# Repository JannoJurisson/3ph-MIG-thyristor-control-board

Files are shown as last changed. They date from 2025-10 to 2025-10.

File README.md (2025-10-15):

# 3ph-MIG-thyristor-control-board
Control board for my DIY 3 phase MIG welder that uses six thyristors(SCR) for rectifying the output of a old, soviet era three phase isolation transformer (~5kW). 
Raspberry Pico board is used to monitor and control all the functions

## Board Specifications

| Feature | Description |
| :--- | :--- |
| **Power Input** | +24V DC |
| **Current Control** | Potentiometer adjustment for welding current. |
| **Phase Monitoring** | Isolated inputs for all phases for missing phase detection. |
| **SCR Drive** | Isolated output for six SCRs via ferrite transformers (20KHz). |
| **High-Current Outputs** | Gas solenoid, Main Contactor, Auxiliary Output. |
| **Motor Drivers** | 2x `DRV8825` stepper motor drivers. |
| **User Inputs** | Gun trigger switch, ADC for wire speed/current pots. |
| **Expansion** | `I2C` connector for displays and peripherals. |
| **Special Feature**| Wire motor balancing for dual-motor setups (e.g., spool gun).|

3ph_thyristor controller_top

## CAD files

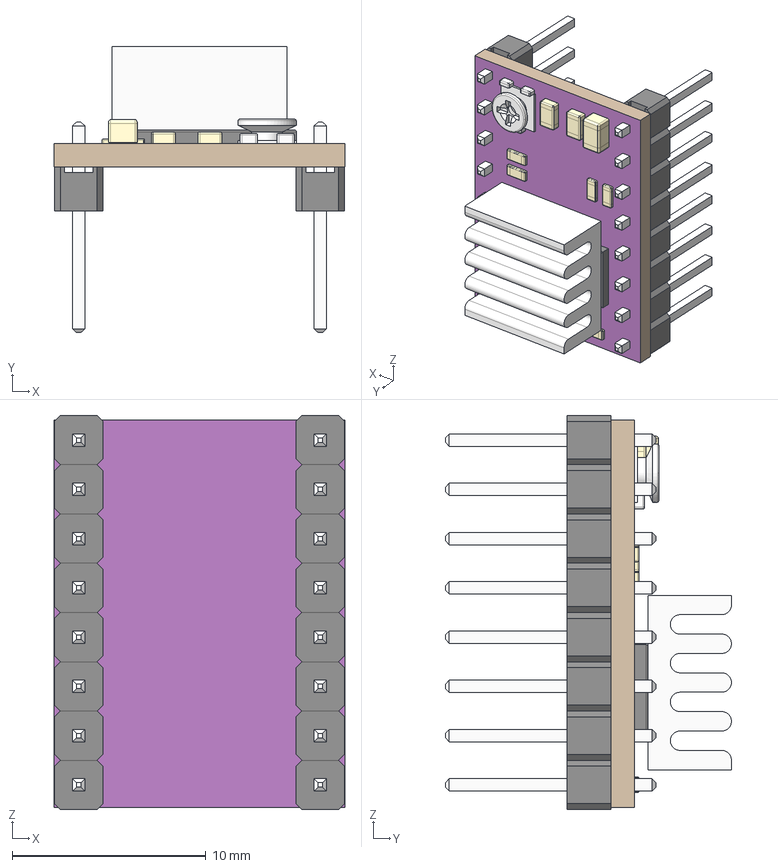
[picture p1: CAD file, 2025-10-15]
KiCAD/3d_models/Driver DRV8825.stp
15.0 x 14.7 x 20.3 mm

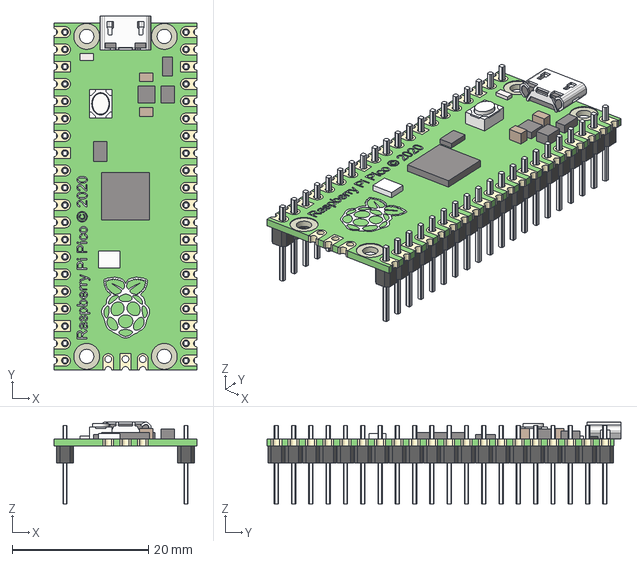
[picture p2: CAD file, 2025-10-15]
KiCAD/3d_models/raspberry pi pico with contacts.step
21.0 x 52.0 x 12.0 mm
ножка x 20
ножка v3(Mirror) x 20

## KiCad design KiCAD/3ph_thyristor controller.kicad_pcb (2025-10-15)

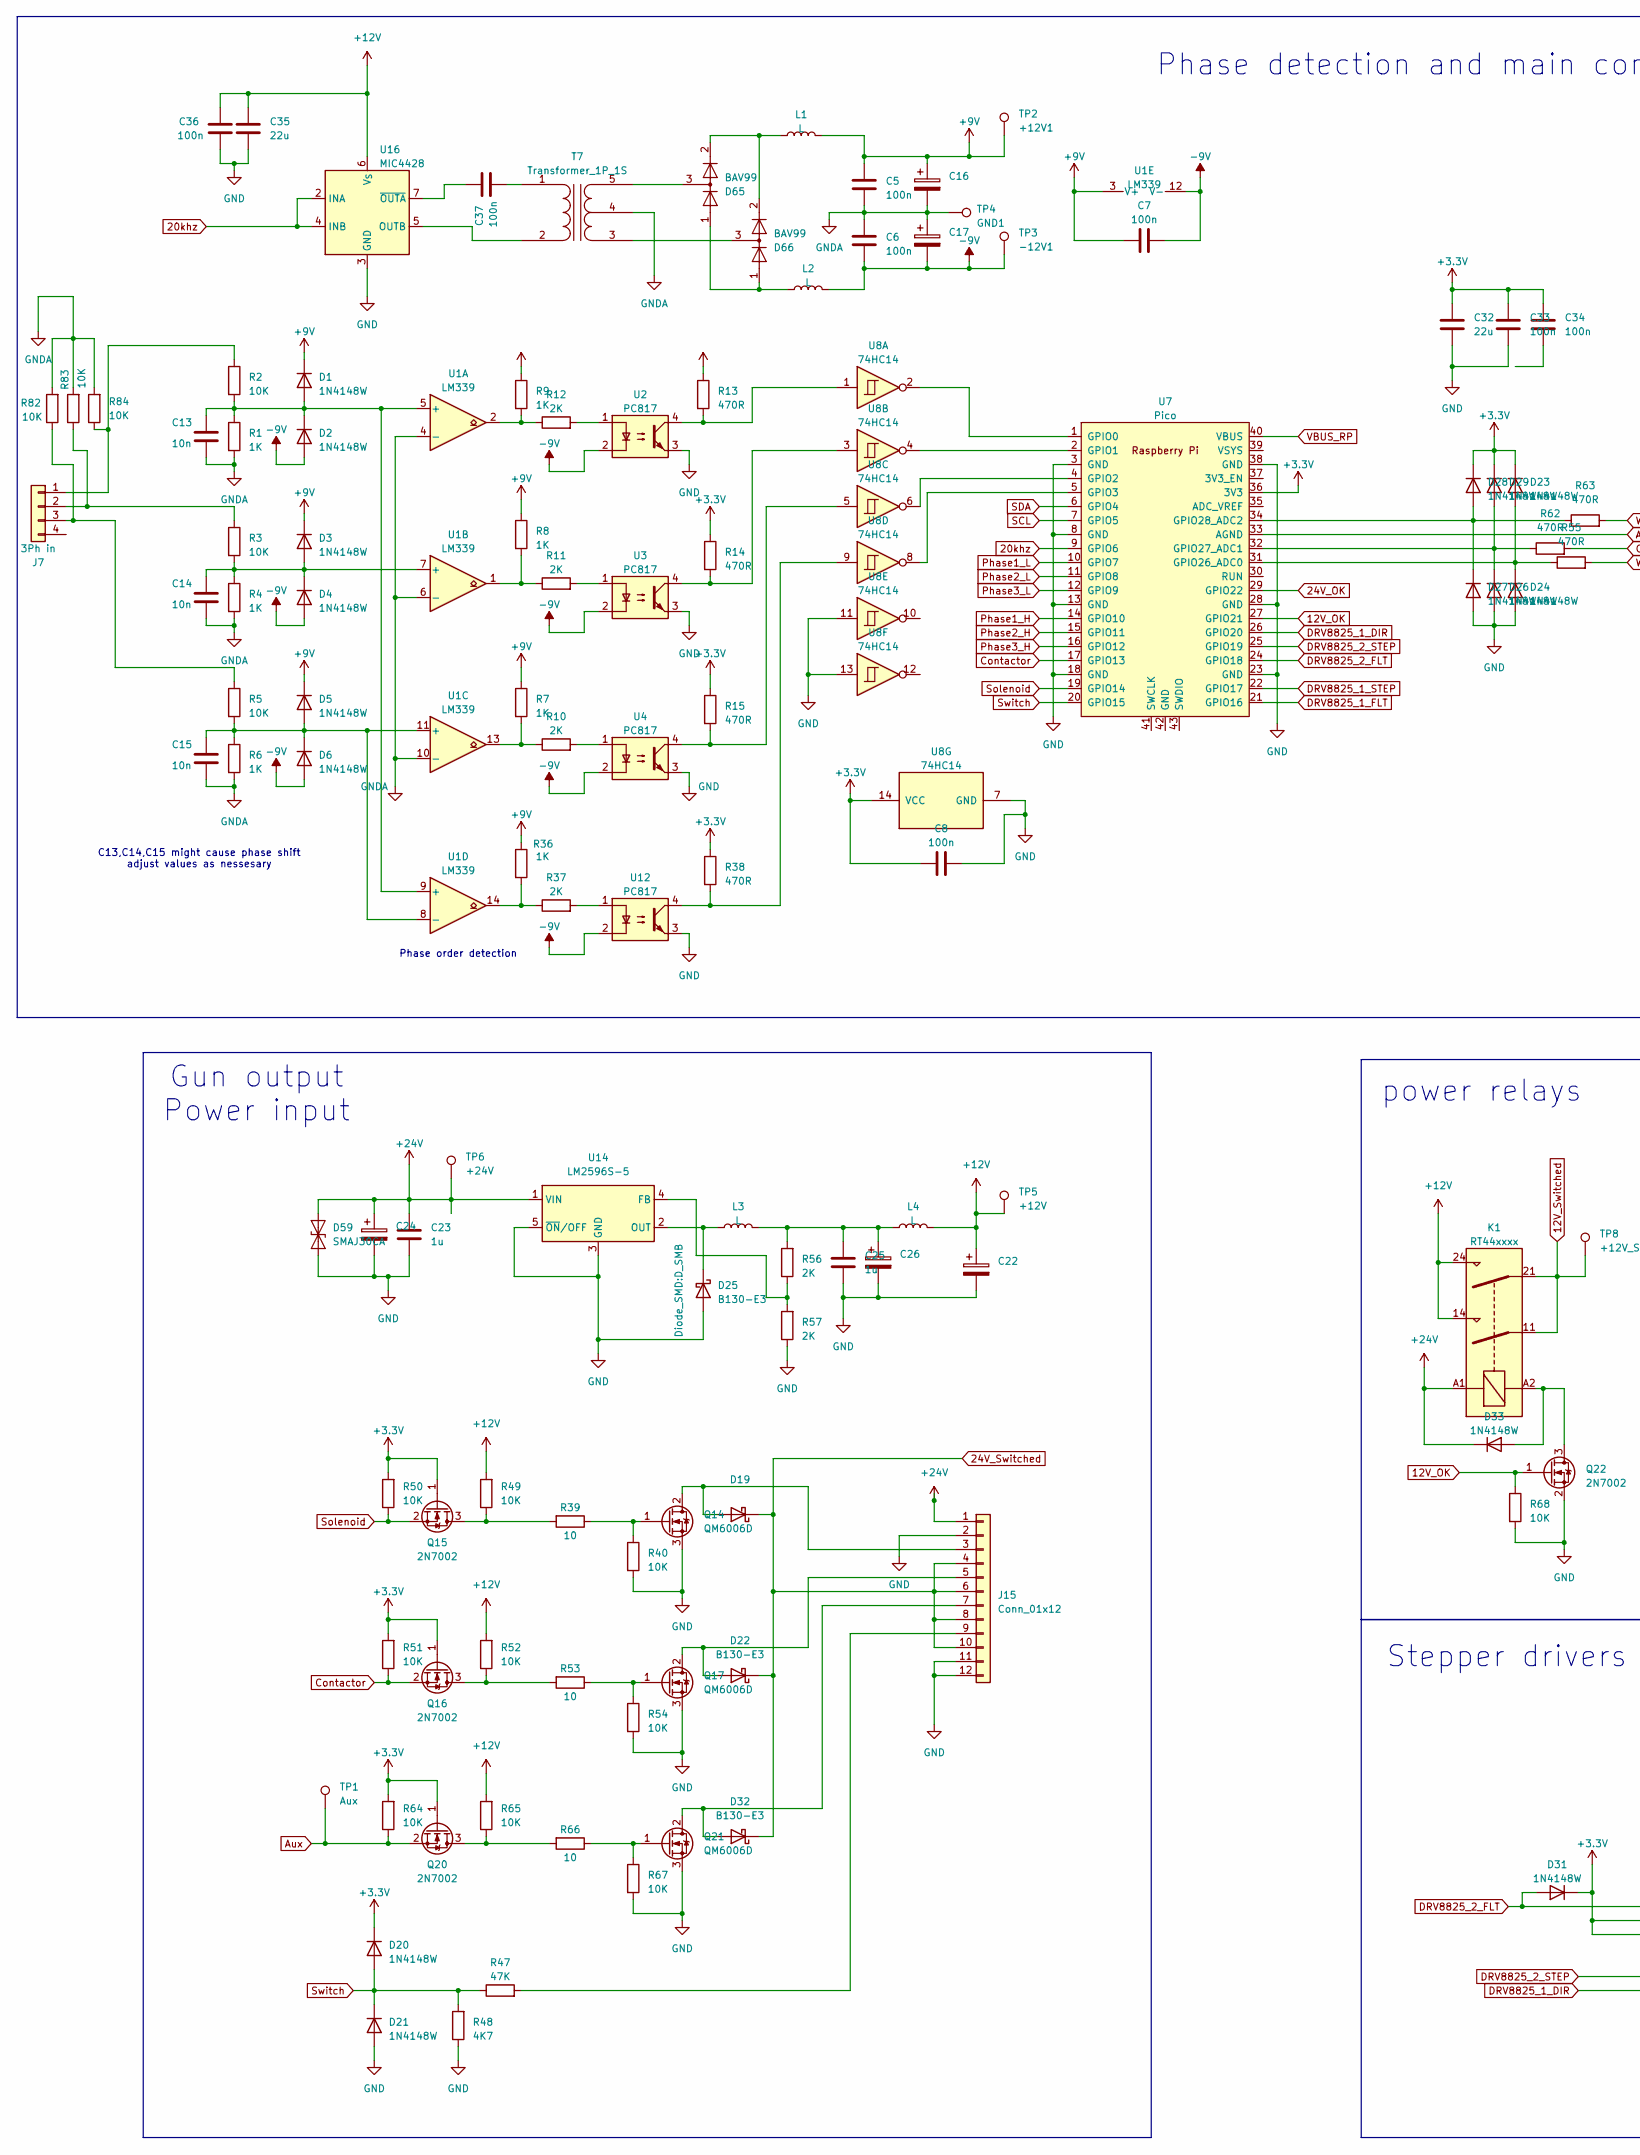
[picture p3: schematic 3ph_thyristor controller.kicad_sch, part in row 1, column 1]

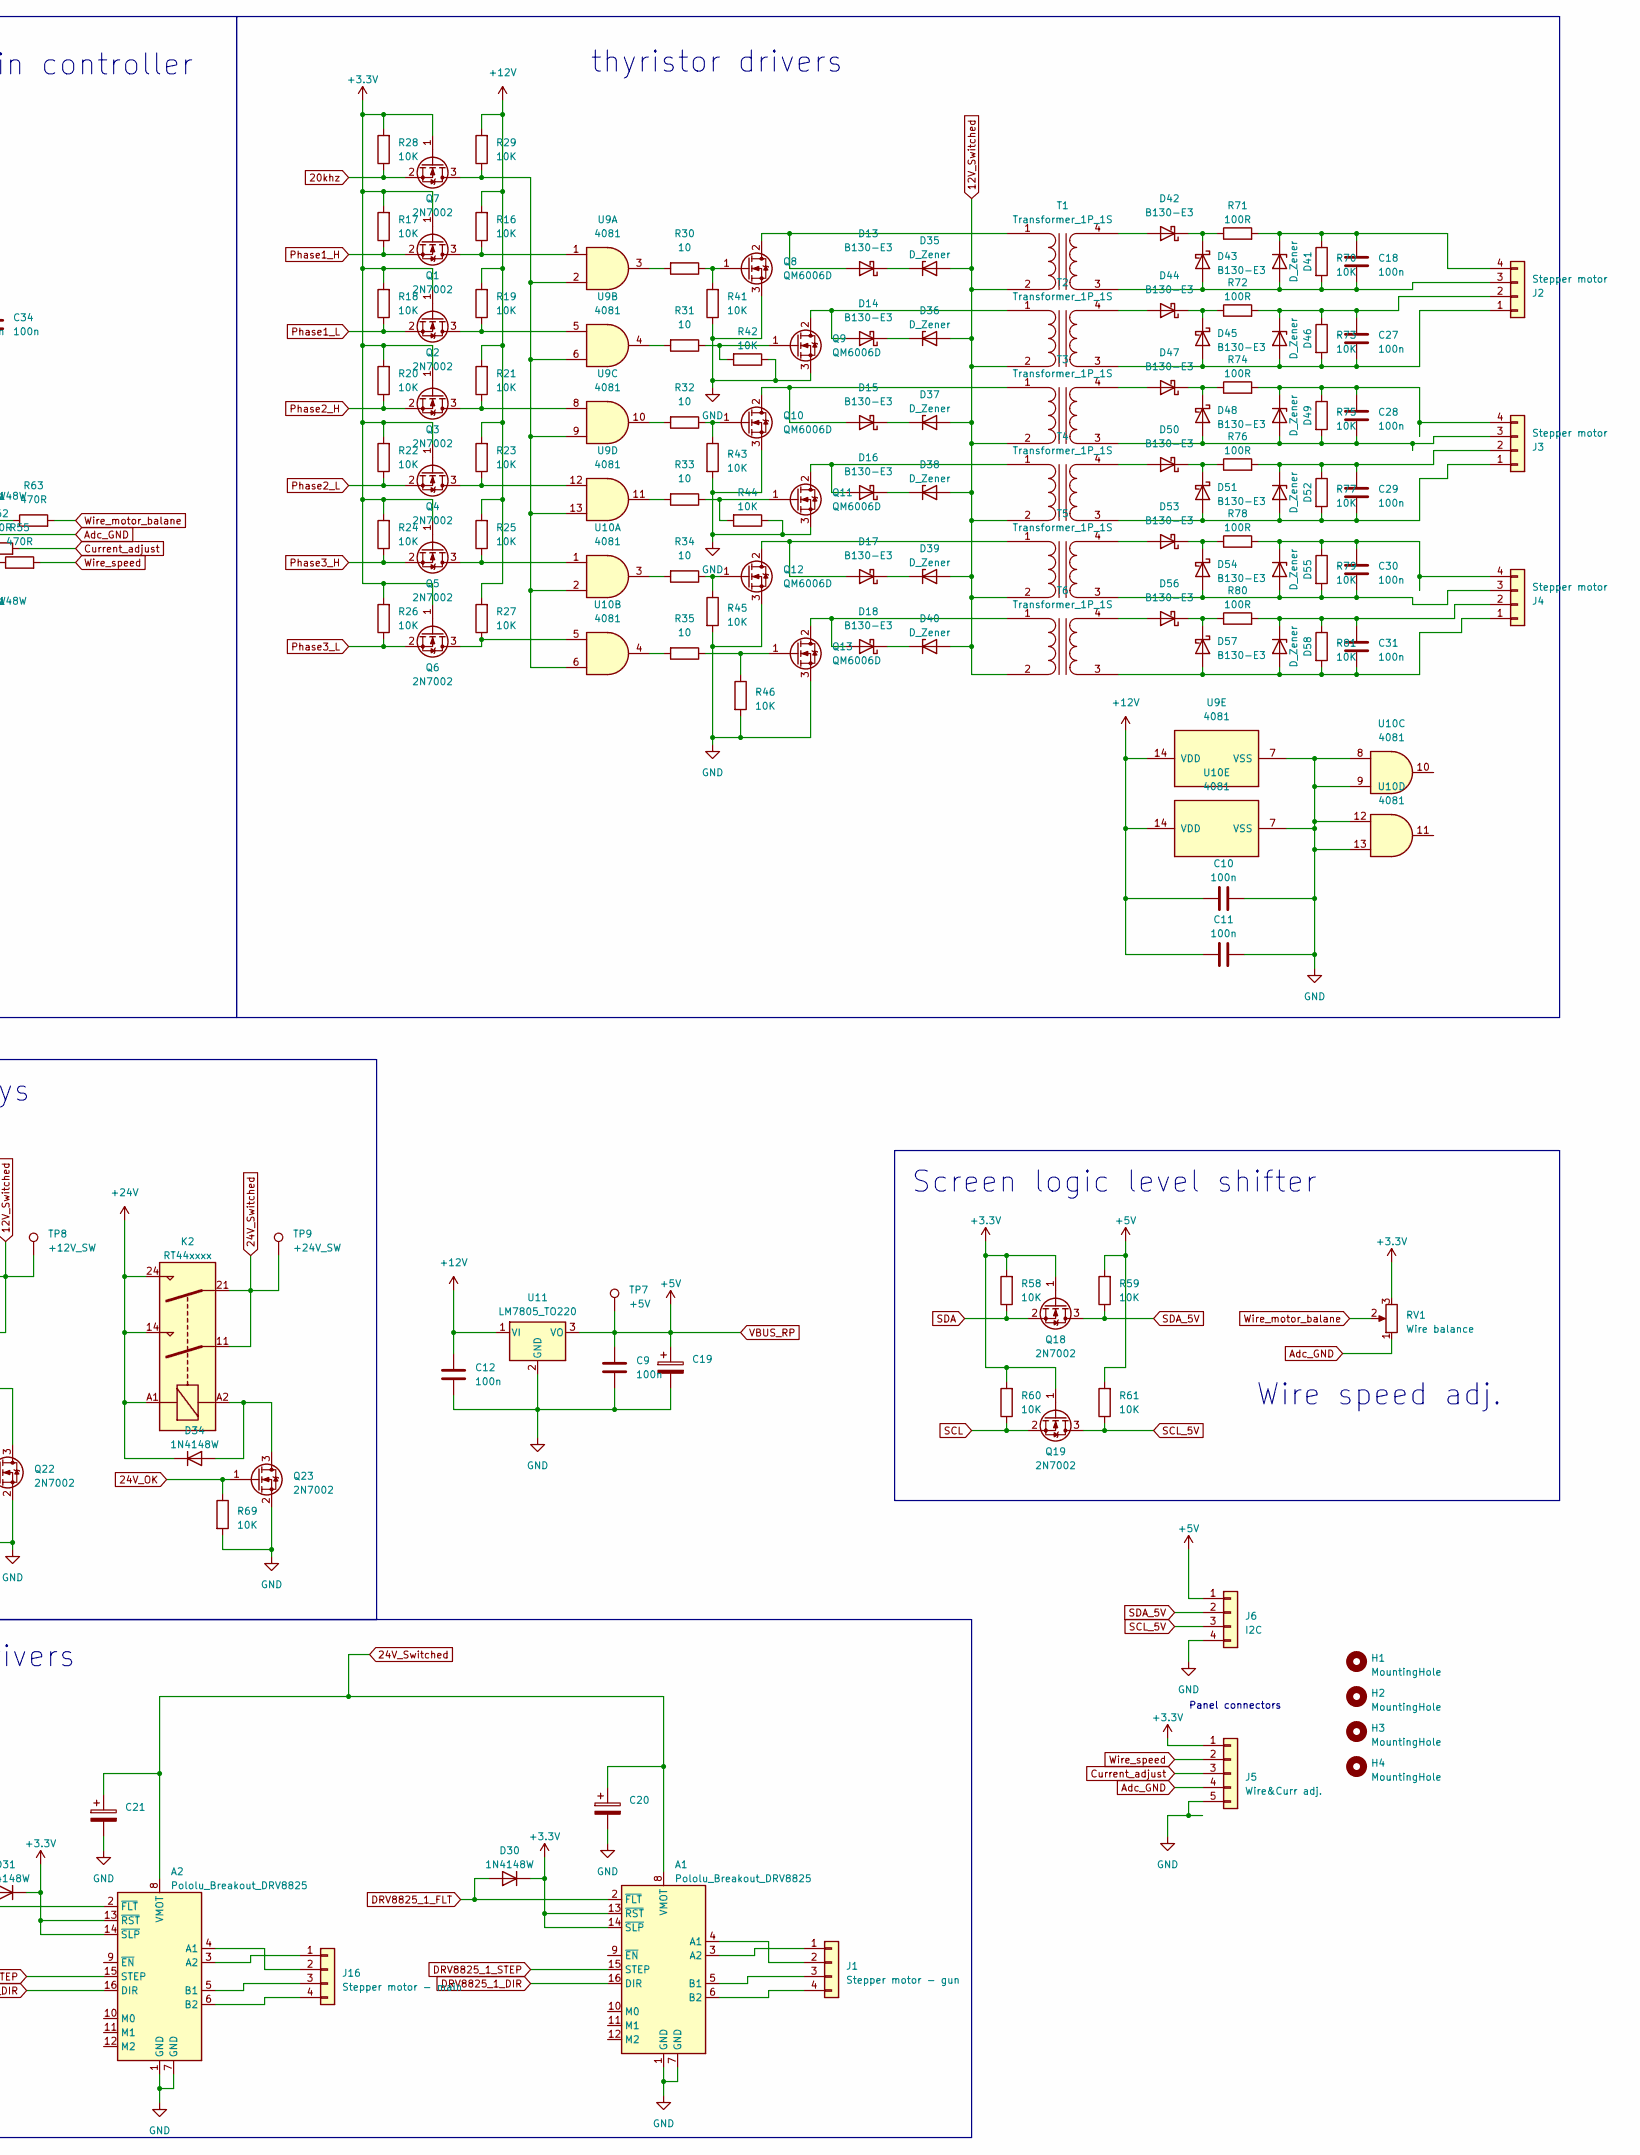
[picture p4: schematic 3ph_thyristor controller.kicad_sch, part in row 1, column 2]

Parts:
A1, A2: Pololu_Breakout_DRV8825; Pololu_Breakout-16_15.2x20.3mm
C5, C6, C7, C8, C9, C10, C11, C12, C18, C27, C28, C29, C30, C31, C33, C34, C36, C37: 100n; C_0805_2012Metric
C13, C14, C15: 10n; C_0805_2012Metric
C16, C17, C19, C20, C21: C_Polarized; CP_Elec_10x10
C22, C24, C26: 220u; CP_Elec_10x10
C23, C25: 1u; C_1206_3216Metric
C32, C35: 22u; C_0805_2012Metric
D1, D2, D3, D4, D5, D6, D20, D21, D23, D24, D26, D27, D28, D29, D30, D31, D33, D34: 1N4148W; D_MiniMELF
D13, D14, D15, D16, D17, D18, D19, D22, D32, D42, D43, D44, D45, D47, D48, D50, D51, D53, D54, D56, D57: B130-E3; D_SMA
D25: B130-E3; D_SMB
D35, D36, D37, D38, D39, D40, D41, D46, D49, D52, D55, D58: D_Zener; D_SMA
D59: SMAJ30CA; D_SMC
D65, D66: BAV99; SOT-23
H1, H2, H3, H4: MountingHole; MountingHole_3.5mm
J1: Stepper motor - gun; PhoenixContact_MSTBA_2,5_4-G_1x04_P5.00mm_Horizontal
J2, J3, J4: Stepper motor; PhoenixContact_MSTBA_2,5_4-G_1x04_P5.00mm_Horizontal
J5: Wire&Curr adj.; Molex_KK-254_AE-6410-05A_1x05_P2.54mm_Vertical
J6: I2C; Molex_KK-254_AE-6410-04A_1x04_P2.54mm_Vertical
J7: 3Ph in; PhoenixContact_MSTBA_2,5_4-G_1x04_P5.00mm_Horizontal
J15: Conn_01x12; PhoenixContact_MC_1,5_12-G-3.5_1x12_P3.50mm_Horizontal
J16: Stepper motor - main; PhoenixContact_MSTBA_2,5_4-G_1x04_P5.00mm_Horizontal
K1, K2: RT44xxxx; Relay_DPST_Schrack-RT2-FormA_RM5mm
L1, L2: L; L_1210_3225Metric_Pad1.42x2.65mm_HandSolder
L3, L4: L; L_Bourns_SRR1260
Q1, Q2, Q3, Q4, Q5, Q6, Q7, Q15, Q16, Q18, Q19, Q20, Q22, Q23: 2N7002; SOT-23
Q8, Q9, Q10, Q11, Q12, Q13, Q14, Q17, Q21: QM6006D; TO-252-2
R1, R4, R6, R7, R8, R9, R36: 1K; R_0805_2012Metric
R2, R3, R5, R16, R17, R18, R19, R20, R21, R22, R23, R24, R25, R26, R27, R28, R29, R40, R41, R42, R43, R44, R45, R46, R49, R50, R51, R52, R54, R58, R59, R60, R61, R64, R65, R67, R68, R69, R70, R73, R75, R77, R79, R81, R82, R83, R84: 10K; R_0805_2012Metric
R10, R11, R12, R37, R56, R57: 2K; R_0805_2012Metric
R13, R14, R15, R38, R55, R62, R63: 470R; R_0805_2012Metric
R30, R31, R32, R33, R34, R35, R39, R53, R66: 10; R_0805_2012Metric
R47: 47K; R_0805_2012Metric
R48: 4K7; R_0805_2012Metric
R71, R72, R74, R76, R78, R80: 100R; R_0805_2012Metric
RV1: Wire balance; Potentiometer_ACP_CA9-V10_Vertical_Hole
T1, T2, T3, T4, T5, T6, T7: Transformer_1P_1S; Transformer_Toroid_Horizontal_D18.0mm
TP1: Aux; TestPoint_Pad_D2.0mm
TP2: +12V1; TestPoint_Pad_D2.0mm
TP3: -12V1; TestPoint_Pad_D2.0mm
TP4: GND1; TestPoint_Pad_D2.0mm
TP5: +12V; TestPoint_Pad_D2.0mm
TP6: +24V; TestPoint_Pad_D2.0mm
TP7: +5V; TestPoint_Pad_D2.0mm
TP8: +12V_SW; TestPoint_Pad_D2.0mm
TP9: +24V_SW; TestPoint_Pad_D2.0mm
U1: LM339; SOIC-14_3.9x8.7mm_P1.27mm
U2, U3, U4, U12: PC817; DIP-4_W7.62mm_SMDSocket_SmallPads
U7: Pico; RPi_Pico_SMD_TH
U8: 74HC14; SOIC-14_3.9x8.7mm_P1.27mm
U9, U10: 4081; SOIC-14_3.9x8.7mm_P1.27mm
U11: LM7805_TO220; TO-252-3_TabPin2
U14: LM2596S-5; TO-263-5_TabPin3
U16: MIC4428; SOIC-8_3.9x4.9mm_P1.27mm

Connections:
12V_OK: Q22.1 (G), R68.1, U7.27 (GPIO21)
12V_Switched: D35.2 (A), D36.2 (A), D37.2 (A), D38.2 (A), D39.2 (A), D40.2 (A), K1.11, K1.21, T1.2 (AB), T2.2 (AB), T3.2 (AB), T4.2 (AB), T5.2 (AB), T6.2 (AB), TP8.1
20khz: Q7.2 (S), R28.1, U7.9 (GPIO6), U16.2 (INA), U16.4 (INB)
24V_OK: Q23.1 (G), R69.1, U7.29 (GPIO22)
24V_Switched: A1.8 (VMOT), A2.8 (VMOT), C20.1, C21.1, D19.1 (K), D22.1 (K), D32.1 (K), J15.4, J15.6, J15.8, J15.10, K2.11, K2.21, TP9.1
+3.3V: A1.13 (~RST), A1.14 (~SLP), A2.13 (~RST), A2.14 (~SLP), C8.1, C32.2, C33.2, C34.2, D20.1 (K), D23.1 (K), D28.1 (K), D29.1 (K), D30.1 (K), D31.1 (K), J5.1, Q1.1 (G), Q2.1 (G), Q3.1 (G), Q4.1 (G), Q5.1 (G), Q6.1 (G), Q7.1 (G), Q15.1 (G), Q16.1 (G), Q18.1 (G), Q19.1 (G), Q20.1 (G), R13.1, R14.1, R15.1, R17.2, R18.2, R20.2, R22.2, R24.2, R26.2, R28.2, R38.1, R50.2, R51.2, R58.2, R60.2, R64.2, RV1.3, U7.36 (3V3), U8.14 (VCC)
+9V: C5.1, C7.1, C16.1, D1.1 (K), D3.1 (K), D5.1 (K), L1.2, R7.1, R8.1, R9.1, R36.1, TP2.1, U1.3 (V+)
+12V: C10.1, C11.1, C12.2, C22.1, C35.2, C36.2, K1.14, K1.24, L4.2, R16.2, R19.2, R21.2, R23.2, R25.2, R27.2, R29.2, R49.2, R52.2, R65.2, TP5.1, U9.14 (VDD), U10.14 (VDD), U11.1 (VI), U16.6 (V_{S})
+24V: C23.2, C24.1, D33.1 (K), D34.1 (K), D59.2 (A2), J15.1, K1.A1, K2.14, K2.24, K2.A1, TP6.1, U14.1 (VIN)
-9V: C6.2, C7.2, C17.2, D2.2 (A), D4.2 (A), D6.2 (A), L2.2, TP3.1, U1.12 (V-), U2.2, U3.2, U4.2, U12.2
Adc_GND: J5.4, RV1.1, U7.33 (AGND)
Aux: Q20.2 (S), R64.1, TP1.1
Contactor: Q16.2 (S), R51.1, U7.17 (GPIO13)
Current_adjust: J5.3, R62.2
DRV8825_1_DIR: A1.16 (DIR), A2.16 (DIR), U7.26 (GPIO20)
DRV8825_1_FLT: A1.2 (~FLT), D30.2 (A), U7.21 (GPIO16)
DRV8825_1_STEP: A1.15 (STEP), U7.22 (GPIO17)
DRV8825_2_FLT: A2.2 (~FLT), D31.2 (A), U7.24 (GPIO18)
DRV8825_2_STEP: A2.15 (STEP), U7.25 (GPIO19)
GND: A1.1 (GND), A1.7 (GND), A2.1 (GND), A2.7 (GND), C8.2, C9.1, C10.2, C11.2, C12.1, C19.2, C20.2, C21.2, C22.2, C23.1, C24.2, C25.1, C26.2, C32.1, C33.1, C35.1, C36.1, D21.2 (A), D24.2 (A), D25.2 (A), D26.2 (A), D27.2 (A), D59.1 (A1), J5.5, J6.4, J15.2, J15.11, J15.12, Q8.3 (S), Q9.3 (S), Q10.3 (S), Q11.3 (S), Q12.3 (S), Q13.3 (S), Q14.3 (S), Q17.3 (S), Q21.3 (S), Q22.2 (S), Q23.2 (S), R40.2, R41.1, R42.1, R43.2, R44.1, R45.2, R46.2, R48.1, R54.2, R57.1, R67.2, R68.2, R69.2, U2.3, U3.3, U4.3, U7.3 (GND), U7.8 (GND), U7.13 (GND), U7.18 (GND), U7.23 (GND), U7.28 (GND), U7.38 (GND), U8.7 (GND), U8.11, U8.13, U9.7 (VSS), U10.7 (VSS), U10.8, U10.9, U10.12, U10.13, U11.2 (GND), U12.3, U14.3 (GND), U14.5 (~ON/OFF), U16.3 (GND)
GNDA: C5.2, C6.1, C13.2, C14.2, C15.2, C16.2, C17.1, R1.2, R4.2, R6.2, R82.2, R83.2, R84.2, T7.4 (SA), TP4.1, U1.4 (-), U1.6 (-), U1.10 (-)
unnamed: A1.4 (A1), J1.2
unnamed: A1.3 (A2), J1.1
unnamed: A1.5 (B1), J1.3
unnamed: A1.6 (B2), J1.4
unnamed: A2.4 (A1), J16.2
unnamed: A2.3 (A2), J16.1
unnamed: A2.5 (B1), J16.3
unnamed: A2.6 (B2), J16.4
unnamed: C25.2, C26.1, L3.2, L4.1, R56.2
unnamed: C13.1, D1.2 (A), D2.1 (K), R1.1, R2.2, U1.5 (+), U1.9 (+)
unnamed: C14.1, D3.2 (A), D4.1 (K), R3.2, R4.1, U1.7 (+)
unnamed: C15.1, D5.2 (A), D6.1 (K), R5.2, R6.1, U1.8 (-), U1.11 (+)
unnamed: D13.2 (A), Q8.2 (D), T1.1 (AA)
unnamed: D13.1 (K), D35.1 (K)
unnamed: D14.2 (A), Q9.2 (D), T2.1 (AA)
unnamed: D14.1 (K), D36.1 (K)
unnamed: D15.2 (A), Q10.2 (D), T3.1 (AA)
unnamed: D15.1 (K), D37.1 (K)
unnamed: D16.2 (A), Q11.2 (D), T4.1 (AA)
unnamed: D16.1 (K), D38.1 (K)
unnamed: D17.2 (A), Q12.2 (D), T5.1 (AA)
unnamed: D17.1 (K), D39.1 (K)
unnamed: D18.2 (A), Q13.2 (D), T6.1 (AA)
unnamed: D18.1 (K), D40.1 (K)
unnamed: D19.2 (A), J15.3, Q14.2 (D)
unnamed: D22.2 (A), J15.5, Q17.2 (D)
unnamed: D23.2 (A), D24.1 (K), R55.1, U7.31 (GPIO26_ADC0)
unnamed: D25.1 (K), L3.1, U14.2 (OUT)
unnamed: D26.1 (K), D29.2 (A), R62.1, U7.32 (GPIO27_ADC1)
unnamed: D27.1 (K), D28.2 (A), R63.1, U7.34 (GPIO28_ADC2)
unnamed: D32.2 (A), J15.7, Q21.2 (D)
unnamed: D33.2 (A), K1.A2, Q22.3 (D)
unnamed: D34.2 (A), K2.A2, Q23.3 (D)
unnamed: C18.1, D41.2 (A), D43.2 (A), J2.3, R70.2, T1.3 (SA)
unnamed: C18.2, D41.1 (K), J2.4, R70.1, R71.2
unnamed: D42.2 (A), T1.4 (SB)
unnamed: D42.1 (K), D43.1 (K), R71.1
unnamed: D44.2 (A), T2.4 (SB)
unnamed: D44.1 (K), D45.1 (K), R72.1
unnamed: C27.1, D45.2 (A), D46.2 (A), J2.1, R73.2, T2.3 (SA)
unnamed: C27.2, D46.1 (K), J2.2, R72.2, R73.1
unnamed: D47.2 (A), T3.4 (SB)
unnamed: D47.1 (K), D48.1 (K), R74.1
unnamed: C28.1, D48.2 (A), D49.2 (A), J3.3, R75.2, T3.3 (SA)
unnamed: C28.2, D49.1 (K), J3.4, R74.2, R75.1
unnamed: D50.2 (A), T4.4 (SB)
unnamed: D50.1 (K), D51.1 (K), R76.1
unnamed: C29.1, D51.2 (A), D52.2 (A), J3.1, R77.2, T4.3 (SA)
unnamed: C29.2, D52.1 (K), J3.2, R76.2, R77.1
unnamed: D53.2 (A), T5.4 (SB)
unnamed: D53.1 (K), D54.1 (K), R78.1
unnamed: C30.1, D54.2 (A), D55.2 (A), J4.3, R79.2, T5.3 (SA)
unnamed: C30.2, D55.1 (K), J4.4, R78.2, R79.1
unnamed: D56.2 (A), T6.4 (SB)
unnamed: D56.1 (K), D57.1 (K), R80.1
unnamed: C31.1, D57.2 (A), D58.2 (A), J4.1, R81.2, T6.3 (SA)
unnamed: C31.2, D58.1 (K), J4.2, R80.2, R81.1
unnamed: D65.2 (A), D66.2 (A), L1.1
unnamed: D65.1 (K), D66.1 (K), L2.1
unnamed: D66.3 (K), T7.3 (SA)
unnamed: J7.1, R2.1, R84.1
unnamed: J7.2, R3.1, R83.1
unnamed: J7.3, R5.1, R82.1
unnamed: J15.9, R47.2
unnamed: Q1.3 (D), R16.1, U9.1
unnamed: Q2.3 (D), R19.1, U9.5
unnamed: Q3.3 (D), R21.1, U9.8
unnamed: Q4.3 (D), R23.1, U9.12
unnamed: Q5.3 (D), R25.1, U10.1
unnamed: Q6.3 (D), R27.1, U10.5
unnamed: Q7.3 (D), R29.1, U9.2, U9.6, U9.9, U9.13, U10.2, U10.6
unnamed: Q8.1 (G), R30.1, R41.2
unnamed: Q9.1 (G), R31.1, R42.2
unnamed: Q10.1 (G), R32.1, R43.1
unnamed: Q11.1 (G), R33.1, R44.2
unnamed: Q12.1 (G), R34.1, R45.1
unnamed: Q13.1 (G), R35.1, R46.1
unnamed: Q14.1 (G), R39.1, R40.1
unnamed: Q15.3 (D), R39.2, R49.1
unnamed: Q16.3 (D), R52.1, R53.2
unnamed: Q17.1 (G), R53.1, R54.1
unnamed: Q20.3 (D), R65.1, R66.2
unnamed: Q21.1 (G), R66.1, R67.1
unnamed: R7.2, R10.1, U1.13
unnamed: R10.2, U4.1
unnamed: R8.2, R11.1, U1.1
unnamed: R11.2, U3.1
unnamed: R9.2, R12.1, U1.2
unnamed: R12.2, U2.1
unnamed: R13.2, U2.4, U8.1
unnamed: R14.2, U3.4, U8.3
unnamed: R15.2, U4.4, U8.5
unnamed: R30.2, U9.3
unnamed: R31.2, U9.4
unnamed: R32.2, U9.10
unnamed: R33.2, U9.11
unnamed: R34.2, U10.3
unnamed: R35.2, U10.4
unnamed: R36.2, R37.1, U1.14
unnamed: R37.2, U12.1
unnamed: R38.2, U8.9, U12.4
unnamed: C37.1, T7.1 (AA)
unnamed: T7.2 (AB), U16.5 (OUTB)
unnamed: D65.3 (K), T7.5 (SB)
unnamed: U7.1 (GPIO0), U8.2
unnamed: U7.2 (GPIO1), U8.4
unnamed: U7.4 (GPIO2), U8.6
unnamed: U7.5 (GPIO3), U8.8
unnamed: R56.1, R57.2, U14.4 (FB)
unnamed: C37.2, U16.7 (~OUTA)
Phase1_H: Q1.2 (S), R17.1, U7.14 (GPIO10)
Phase1_L: Q2.2 (S), R18.1, U7.10 (GPIO7)
Phase2_H: Q3.2 (S), R20.1, U7.15 (GPIO11)
Phase2_L: Q4.2 (S), R22.1, U7.11 (GPIO8)
Phase3_H: Q5.2 (S), R24.1, U7.16 (GPIO12)
Phase3_L: Q6.2 (S), R26.1, U7.12 (GPIO9)
SCL: Q19.2 (S), R60.1, U7.7 (GPIO5)
SCL_5V: J6.3, Q19.3 (D), R61.1
SDA: Q18.2 (S), R58.1, U7.6 (GPIO4)
SDA_5V: J6.2, Q18.3 (D), R59.1
Solenoid: Q15.2 (S), R50.1, U7.19 (GPIO14)
Switch: D20.2 (A), D21.1 (K), R47.1, R48.2, U7.20 (GPIO15)
VBUS_RP: C9.2, C19.1, J6.1, R59.2, R61.2, TP7.1, U7.40 (VBUS), U11.3 (VO)
Wire_motor_balane: R63.2, RV1.2
Wire_speed: J5.2, R55.2

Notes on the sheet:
Phase order detection
Gun output Power input
Phase detection and main controller
Screen logic level shifter
power relays
Wire speed adj.
thyristor drivers
C13,C14,C15 might cause phase shift adjust values as nessesary
Stepper drivers
Panel connectors

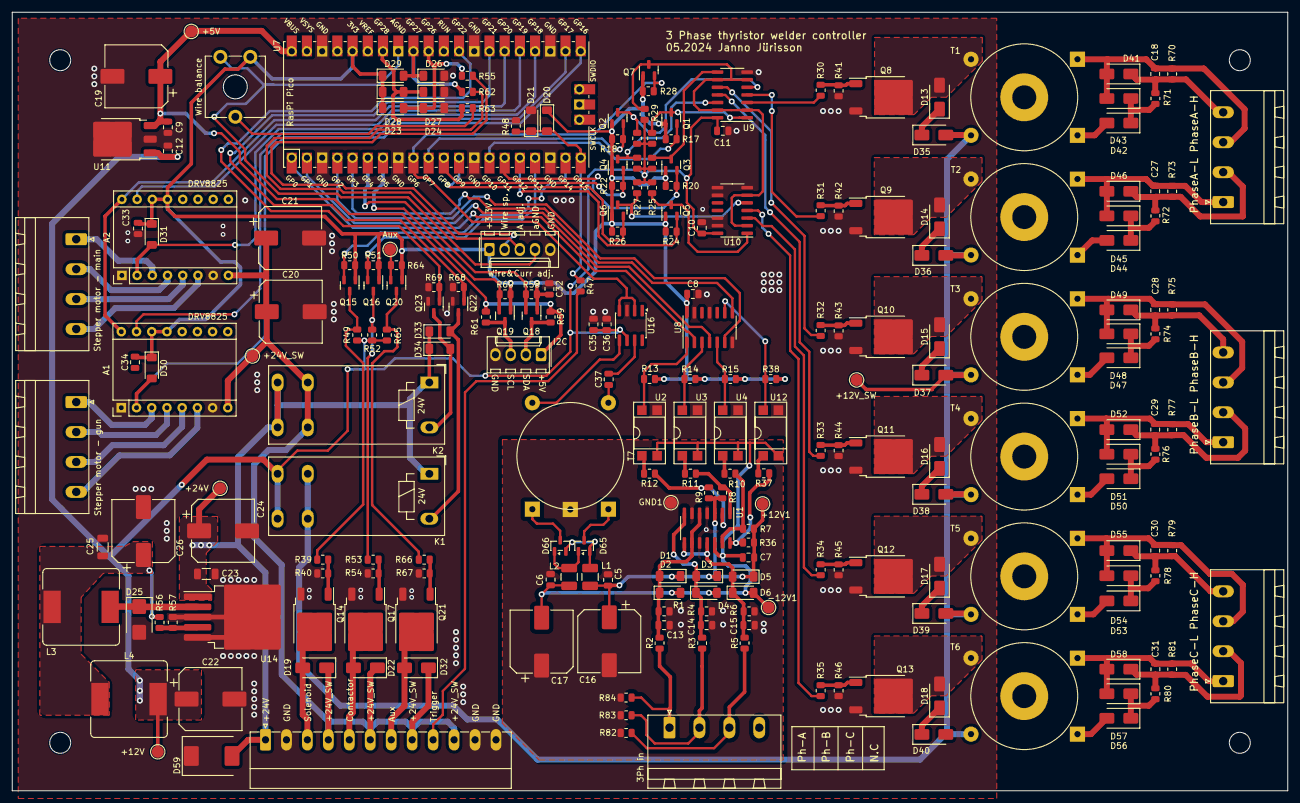
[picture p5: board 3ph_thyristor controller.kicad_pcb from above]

Board: 2 copper layers, 213.0 x 130.0 mm, 245 parts (0 on the bottom side), 146 nets.
